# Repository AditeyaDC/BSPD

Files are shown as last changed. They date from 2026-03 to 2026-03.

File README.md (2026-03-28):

# BSPD RZ-XX6-C/E — Brake System Plausibility Device
**Ashwa Racing 27**  
Designed by Aditeya Sarkar

---

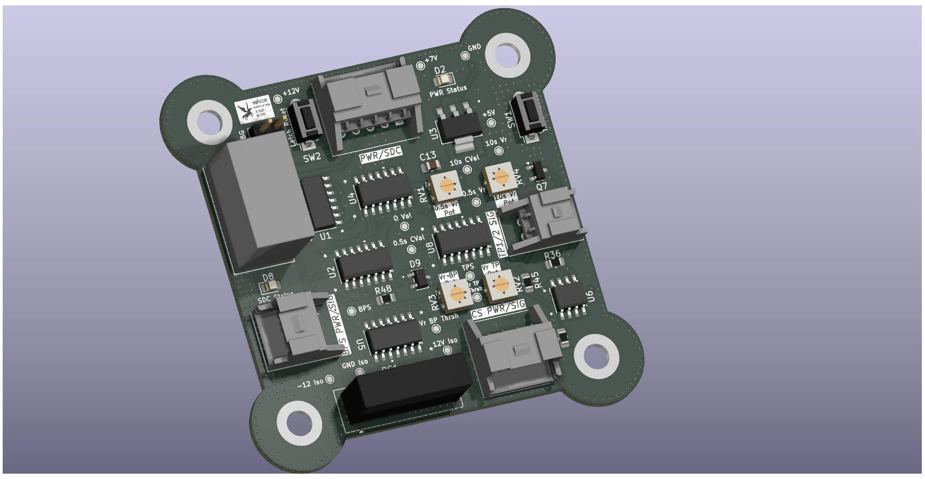
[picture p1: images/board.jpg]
BSPD board


## What is a BSPD?

The Brake System Plausibility Device is a mandatory safety circuit in FSAE/Formula Student vehicles. Its job is to cut power to the motor (via the Shutdown Circuit / SDC) if the driver simultaneously applies heavy braking and demands significant throttle — a condition that should never happen during normal operation and indicates either a pedal fault or a stuck throttle.

This design targets the **FSG CV+EV rules** (with CV mode support via a jumper) and is built entirely out of discrete analog logic — no microcontroller involved.

---

## Block Diagram / Signal Flow

```
Connectors (BPS, TPS, SDC)
        │
        ▼
Current Sensor (EV only)          ←── Biasing circuit converts ±4V diff → 0.5–4.5V
        │
        ▼
Implausibility/Plausibility Check  ←── 500ms timer + 10s timer + comparators
        │
        ▼
SCS Check (Short Circuit Safety)
        │
        ▼
Reset System (SR latch + Power-on reset)
        │
        ▼
Relay (SDC_OUT → cuts motor power / fuel pump)
        │
        ▼
Back to Connectors
```

> Signal flow as annotated in the schematic (Sheet 1/9)

---

## Schematic Overview

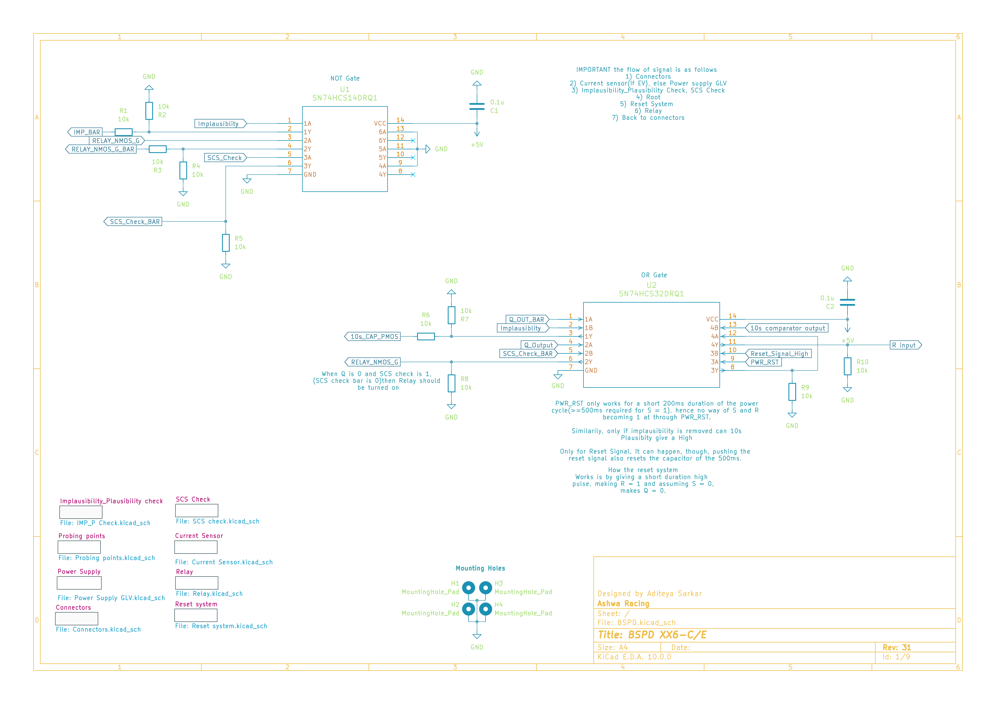
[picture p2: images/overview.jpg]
BSPD Top-Level Overview


The top-level sheet ties everything together. The core logic sits around a **SN74HCS14DRQ1** (Schmitt-trigger inverter, U1) and a **SN74HCS32DRQ1** (OR gate, U2), with the relay controlled by a NMOS gate driven off `RELAY_NMOS_G_BAR`.

---

## Subsystems

### 1. Power Supply

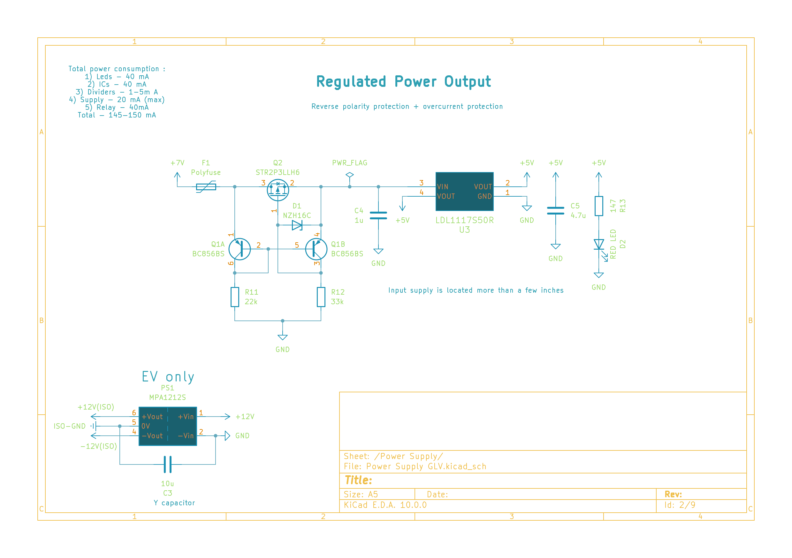
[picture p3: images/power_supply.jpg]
Power Supply


Input is +7V from the car's GLV (Grounded Low Voltage) supply. The board generates a regulated **+5V rail** using an **LDL1117S50R** LDO. Protection is handled by:

- **F1** — Polyfuse for overcurrent  
- **Q2 (STR2P3LLH6)** — P-channel MOSFET for reverse polarity protection, driven by a BC856BS transistor pair (Q1A/Q1B)
- **D1 (NZH16C)** — Zener clamp

For EV operation, isolated ±12V rails are generated via an **MPA1212S** DC-DC isolator (PS1), referenced to ISO-GND, with a Y-capacitor (C3, 10µF) for common-mode filtering.

Total board power budget: ~145–150mA (LEDs 40mA + ICs 40mA + dividers ~5mA + relay 40mA + misc).

---

### 2. Implausibility & Plausibility Check

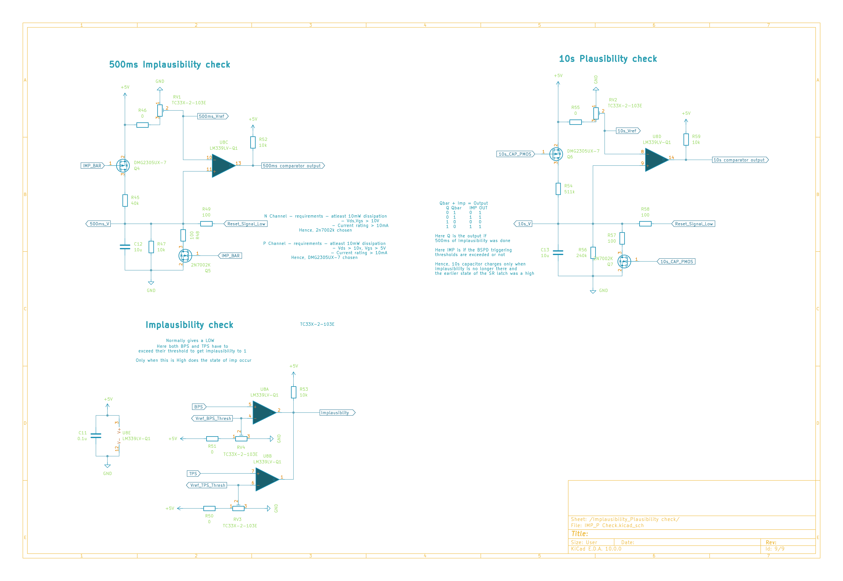
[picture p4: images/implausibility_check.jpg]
Implausibility Check


This is the heart of the BSPD logic. Three comparator circuits run in parallel:

**Implausibility Check** (bottom-left, Sheet 9)  
- Uses **TC33X-2-103E** references and **LM339LV-Q1** comparators
- Both BPS (brake pressure) and TPS (throttle position) must exceed their respective thresholds simultaneously to flag implausibility
- Output: `Implausibility` signal (HIGH = fault)

**500ms Implausibility Timer** (top-left, Sheet 9)  
- Uses a **DMG2305UX-7** complementary MOSFET pair to charge/discharge a capacitor (C12, 10µF + C13) at a controlled rate
- When implausibility is sustained for >500ms, `500ms comparator output` goes HIGH
- The DWC2305UX-7 N-channel requirements: Vth ~1V, Ids up to 10mA → 2N7002K used
- The P-channel: Vth ~−1V, Ids ~10mA → same DWC2305UX-7 (check datasheet for exact variant)

**10s Plausibility Timer** (top-right, Sheet 9)  
- Similar RC-based timing circuit; capacitor (C13) only charges when implausibility is active
- Output: `10s comparator output` — used to latch the fault via the SR latch if the 10s window is exceeded
- `Reset_Signal_Low` can discharge the cap and reset state

---

### 3. Memory Element (SR Latch) + Power Reset

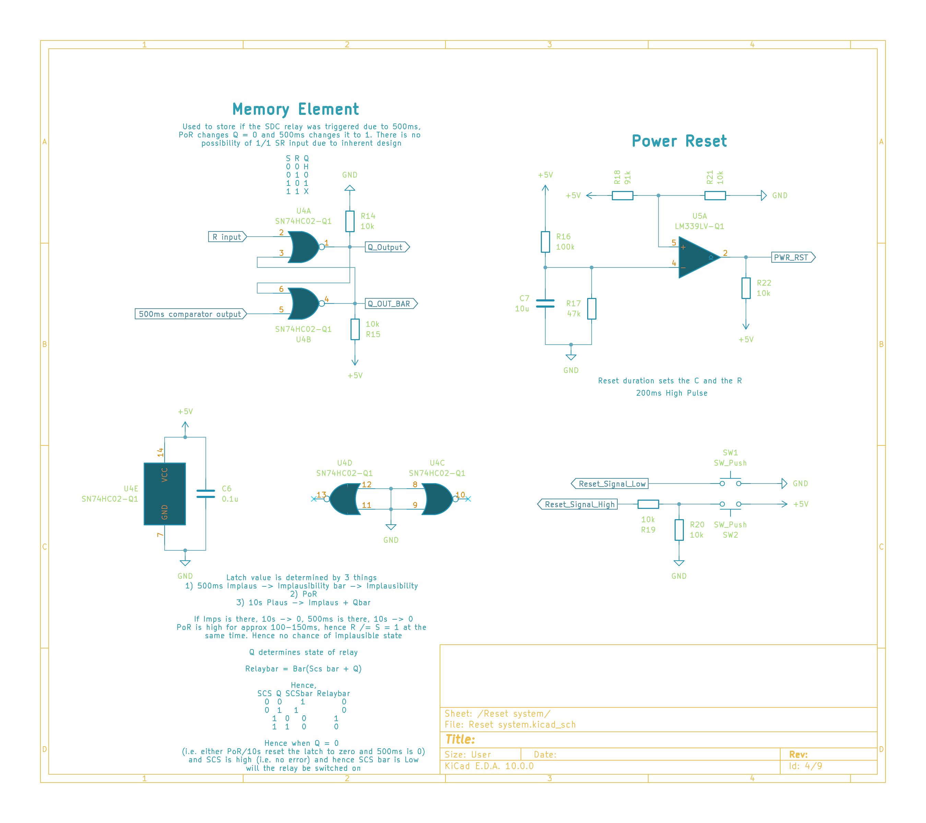
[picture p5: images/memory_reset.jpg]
Memory Element and Reset


**SR Latch** (Sheet 4, left)  
Built from **SN74HC02-Q1** NOR gates (U4A/U4B):

| S (500ms) | R | Q |
|:---:|:-:|:-:|
| 0 | 0 | Hold |
| 0 | 1 | 0 |
| 1 | 0 | 1 |

Q drives `Q_Output` and `Q_OUT_BAR`. The relay state is: `Relaybar = NOR(SCS_bar, Q)`.

So the SDC relay opens (cuts power) only when Q = 0 and SCS_bar is LOW — i.e., no fault and no short circuit detected.

**Power-on Reset** (Sheet 4, right)  
Uses an **LM339LV-Q1** comparator (U5A) with R16 (100k), R17 (47k), and C7 (10µF) to generate a ~200ms HIGH pulse on `PWR_RST` at power-on. This forces the latch into a known state (R = 1 momentarily → Q = 0). Once past the PoR window, R → 0 and normal latch operation resumes.

Two push-buttons (SW1, SW2) provide manual `Reset_Signal_High` / `Reset_Signal_Low` for bench testing.

---

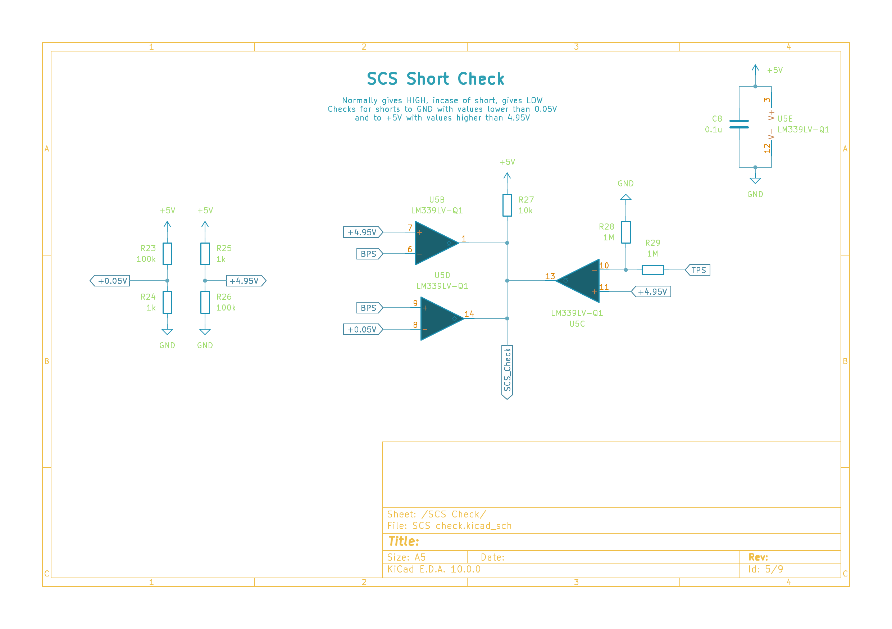
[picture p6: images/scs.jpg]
SCS Check


### 4. SCS Short Circuit Check

The SCS (Short Circuit Safety) check uses **LM339LV-Q1** comparators (U5B/U5D/U5C) to detect wiring faults — specifically shorts to GND (<0.05V) or shorts to +5V (>4.95V) on the BPS and TPS lines.

- Normally: `SCS_Check` = HIGH (no fault)
- On short detection: goes LOW, which blocks the relay from closing regardless of Q

Thresholds set by 100k/1k voltage divider pairs on each input.

---

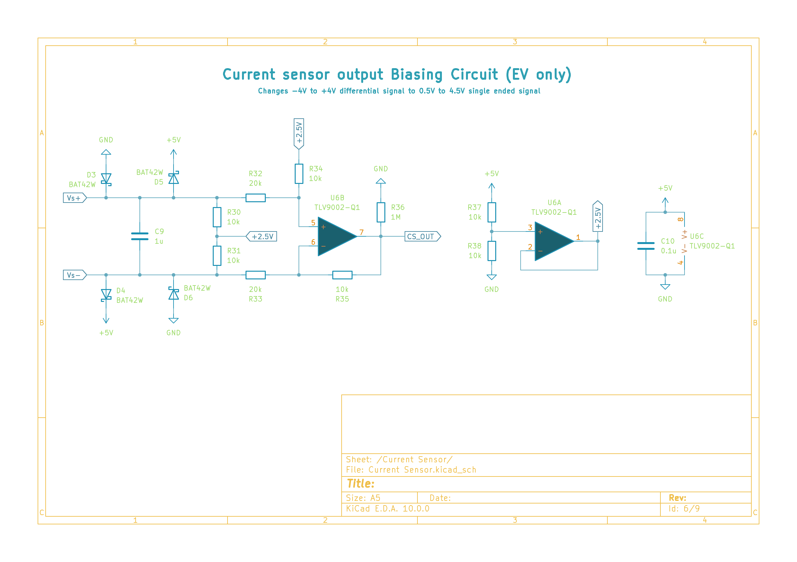
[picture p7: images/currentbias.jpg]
Current Sensor Biasing


### 5. Current Sensor (HB0 300) Biasing (EV Only)

The current sensor (external, connected via J3) outputs a differential signal in the ±4V range. Sheet 6 handles the level shift to a 0.5V–4.5V single-ended signal suitable for the comparators.

- BAT42W Schottky diodes (D3–D6) clamp Vs+ and Vs− to the 0–5V range
- **TLV9002-Q1** op-amps (U6A/U6B) in a difference amplifier config with a +2.5V mid-rail reference
- Output: `CS_OUT` → fed into the implausibility comparator as the throttle-side signal in EV mode
- A jumper on Sheet 8 allows bypassing this for CV (combustion) mode, where TPS1_IN connects directly

---

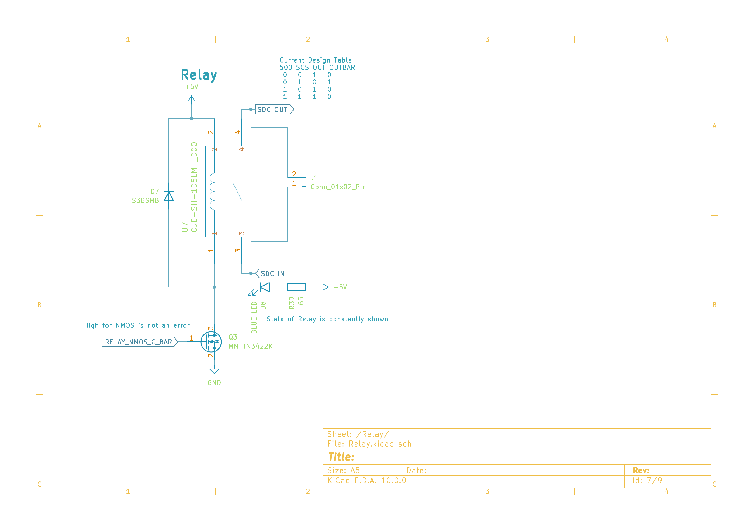
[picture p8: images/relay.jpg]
Relay


### 6. Relay

The SDC relay is an **OJE-SH-105LMH** (U7), driven by an NMOS switch (**MMFTN3422K**, Q3) on the low side. `SDC_OUT` drives the relay coil. A **S3B5MB** diode (D7) provides flyback protection. A blue LED gives constant visual indication of relay state.

---

### 7. Connectors

All external signals come through **TE Connectivity 1744426-series** connectors:

| Connector | Signals |
|---|---|
| J2 (1744426-5) | PWR_FLAG (+7V), GND, +12V, SDC_IN, SDC_OUT |
| J3 (1744426-4) | +12V(ISO), Vs−, Vs+, −12V(ISO) |
| J4 (1744426-3) | GND, BPS_IN, +12V |
| J5 (1744426-2) | TPS1_IN, GND |

BPS scaling: R42 (200Ω) + R43 (430Ω) divider sets `BPS_SCLD` in the 0.88V–4.4V window.  
ESD protection on BPS line via **ESDCAN01-2BLY** (D9).

---

### 8. Probing Points

16 dedicated test points for bench validation:

| TP | Net | TP | Net |
|----|-----|----|-----|
| TP1 | +12V | TP2 | Vref_BPS_Thresh |
| TP3 | +7V | TP4 | 500ms_Vref |
| TP5 | +5V | TP6 | 10s_Vref |
| TP7 | GND | TP8 | Vref_TPS_Thresh |
| TP9 | +12V ISO | TP10 | 10s_V |
| TP11 | GND ISO | TP12 | Q_Output |
| TP13 | −12V ISO | TP14 | 500ms_V |
| TP15 | BPS | TP16 | TPS |

---

## Key ICs

| Part | Function |
|---|---|
| SN74HCS14DRQ1 | Schmitt-trigger inverter (signal conditioning) |
| SN74HCS32DRQ1 | OR gate (implausibility logic) |
| SN74HC02-Q1 | NOR gate SR latch (fault memory) |
| LM339LV-Q1 | Quad comparator (thresholds, SCS, power reset) |
| TLV9002-Q1 | Op-amp (current sensor biasing) |
| LDL1117S50R | 5V LDO regulator |
| MPA1212S | ±12V isolated DC-DC (EV) |
| OJE-SH-105LMH | SDC relay |
| MMFTN3422K | N-channel MOSFET (relay driver) |
| DMG2305UX-7 | Complementary MOSFET pair (timer charging) |

---

## KiCad Version Compatibility

This schematic was designed in **KiCad EDA 10.0.0**.

If you're on KiCad v9 and need to open these files, a downconverted v9-compatible version is available — reach out or raise an issue. The downconversion removes v10-specific fields (like `uuid` blocks and certain footprint attributes) that cause parse errors on older installs.

---

## Repo Structure

```
BSPD/
├── BSPD.kicad_sch              # Top-level schematic
├── Power Supply GLV.kicad_sch
├── Probing points.kicad_sch
├── Reset system.kicad_sch
├── SCS check.kicad_sch
├── Current Sensor.kicad_sch
├── Relay.kicad_sch
├── Connectors.kicad_sch
├── IMP_P_Check.kicad_sch       # Implausibility/Plausibility check
└── README.md
```

---

## Team

**Ashwa Racing — 27**  
R.V. College of Engineering, Bangalore  

Electrical & Testing Subsystem  
Schematic design: Aditeya Sarkar

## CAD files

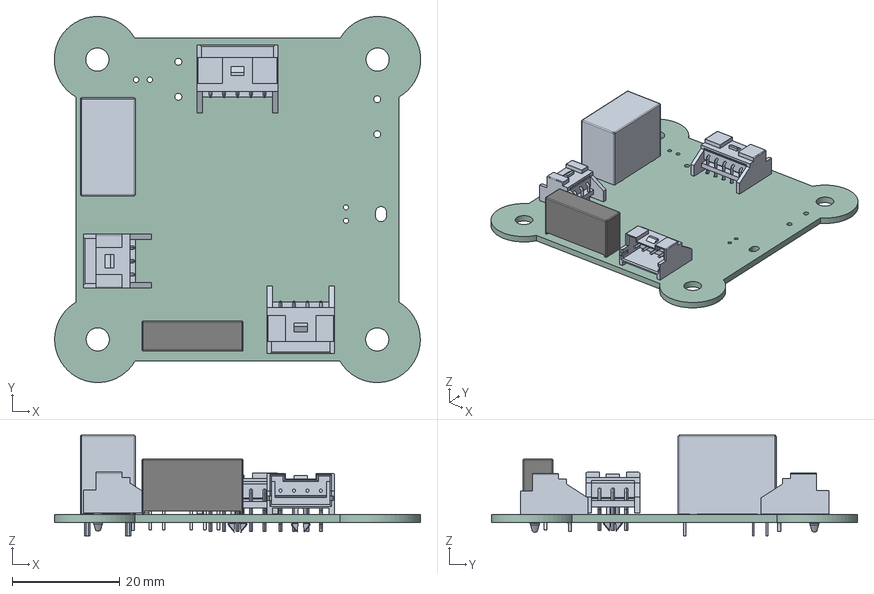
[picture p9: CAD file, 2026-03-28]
BSPD.step
68.0 x 67.9 x 18.7 mm
OJ-SH-105LM,000
Converter_DCDC_XP_POWER-IAxxxxS_THT
BSPD_PCB

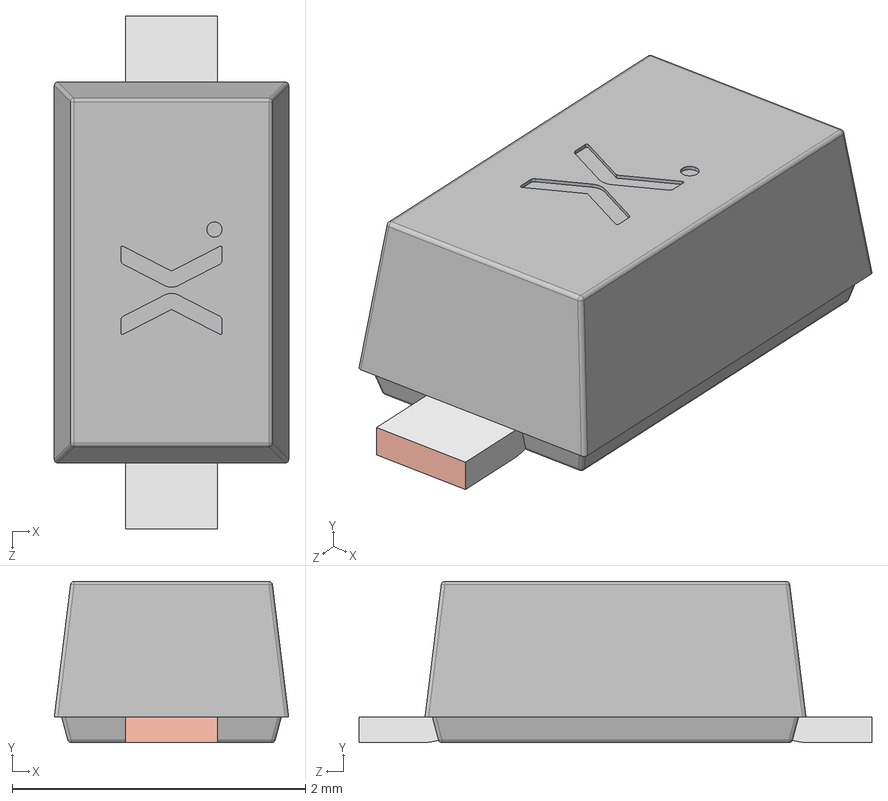
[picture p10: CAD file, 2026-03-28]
KiCad/9.0/3dmodels/SOD123F.step
1.60 x 1.10 x 3.50 mm
SOD123F Lead
SOD123F lower body
SOD123F upper body

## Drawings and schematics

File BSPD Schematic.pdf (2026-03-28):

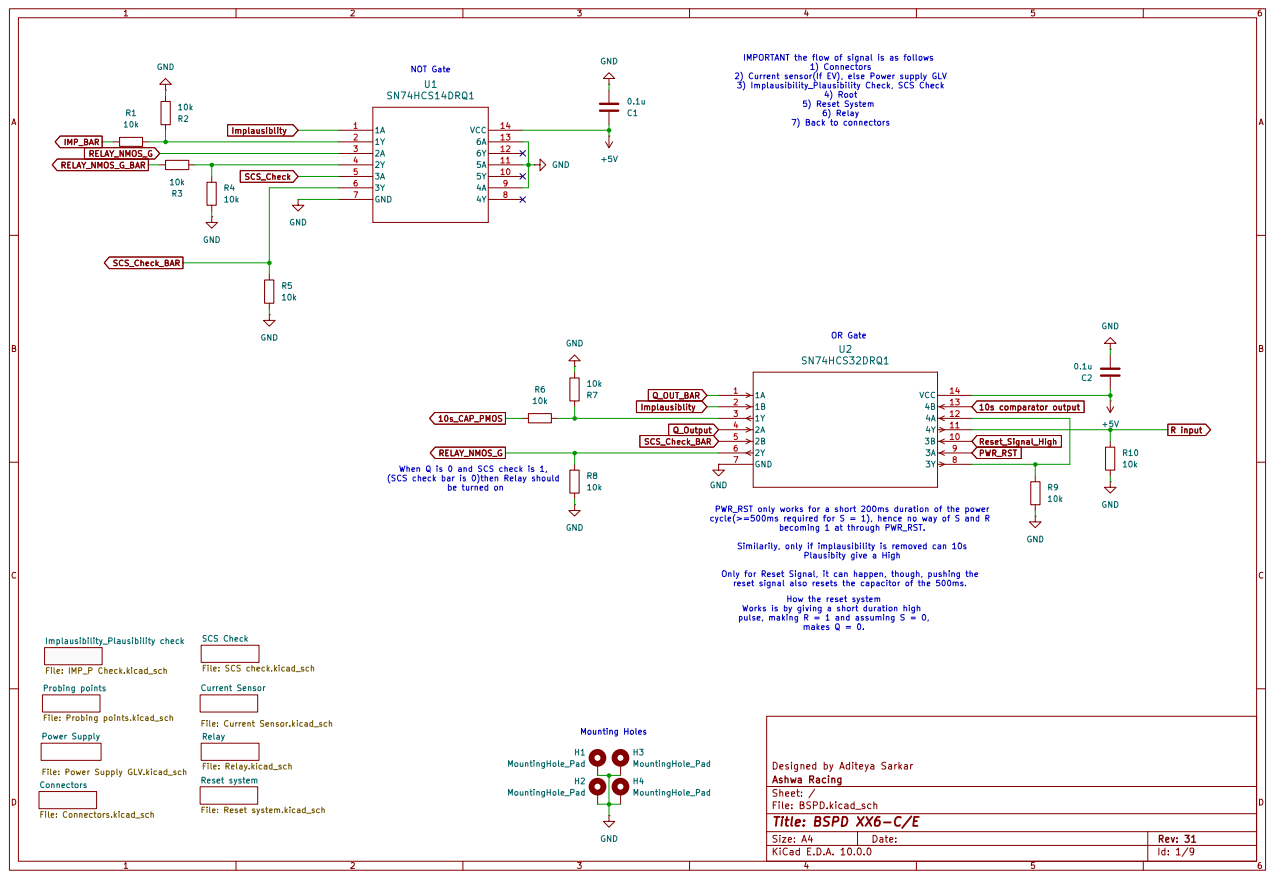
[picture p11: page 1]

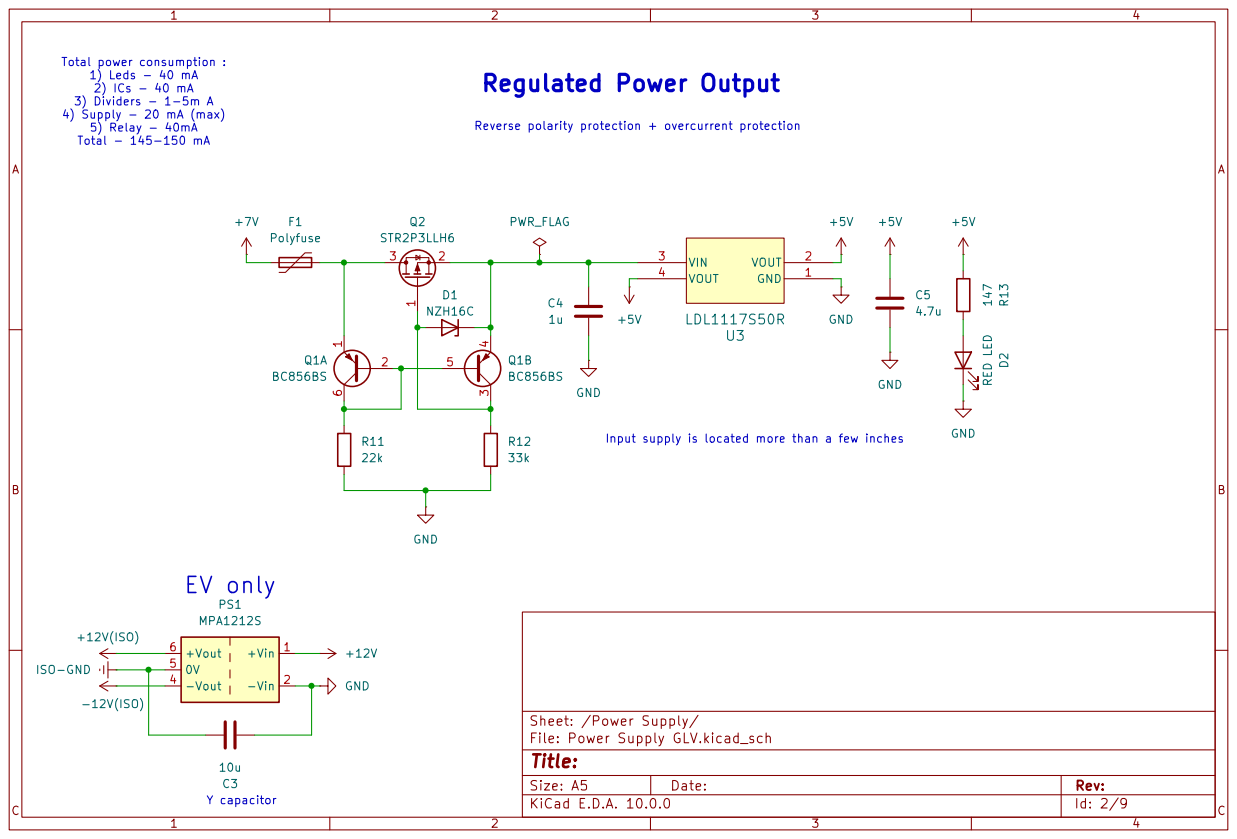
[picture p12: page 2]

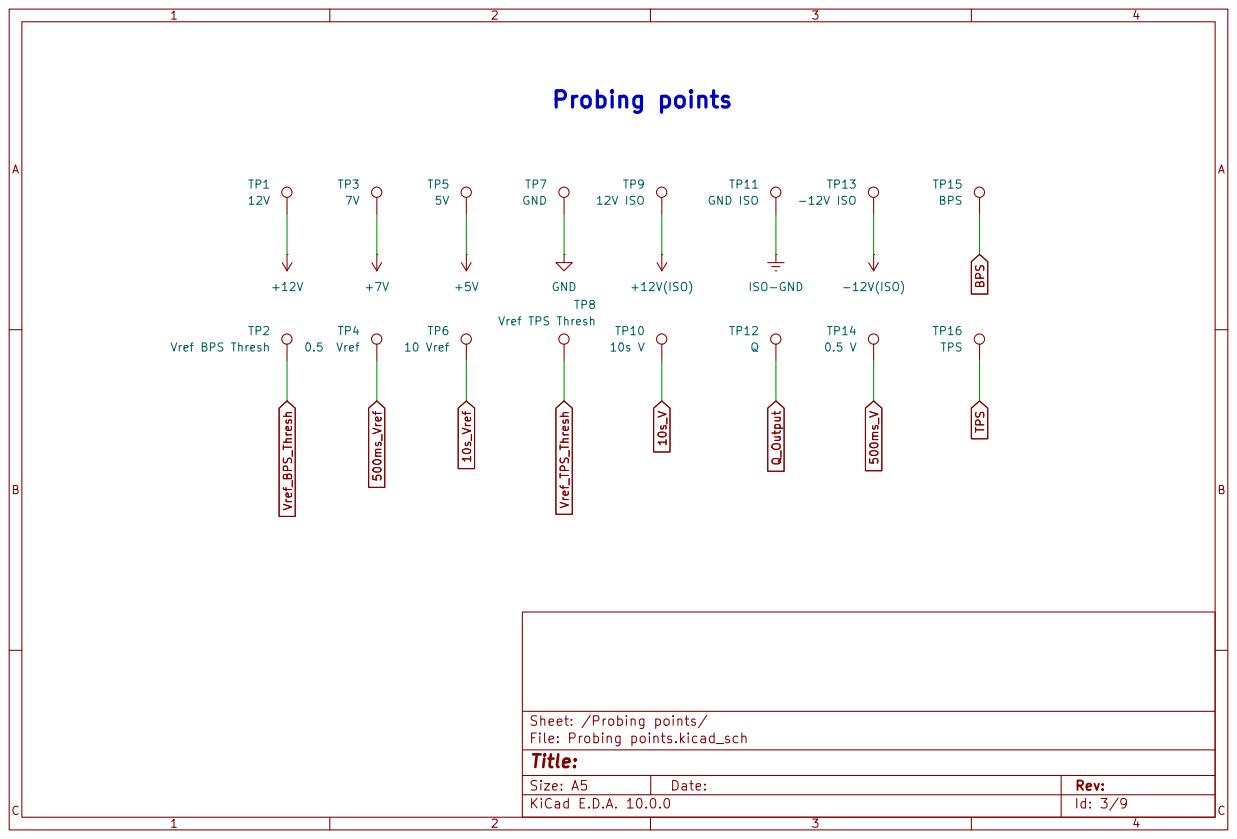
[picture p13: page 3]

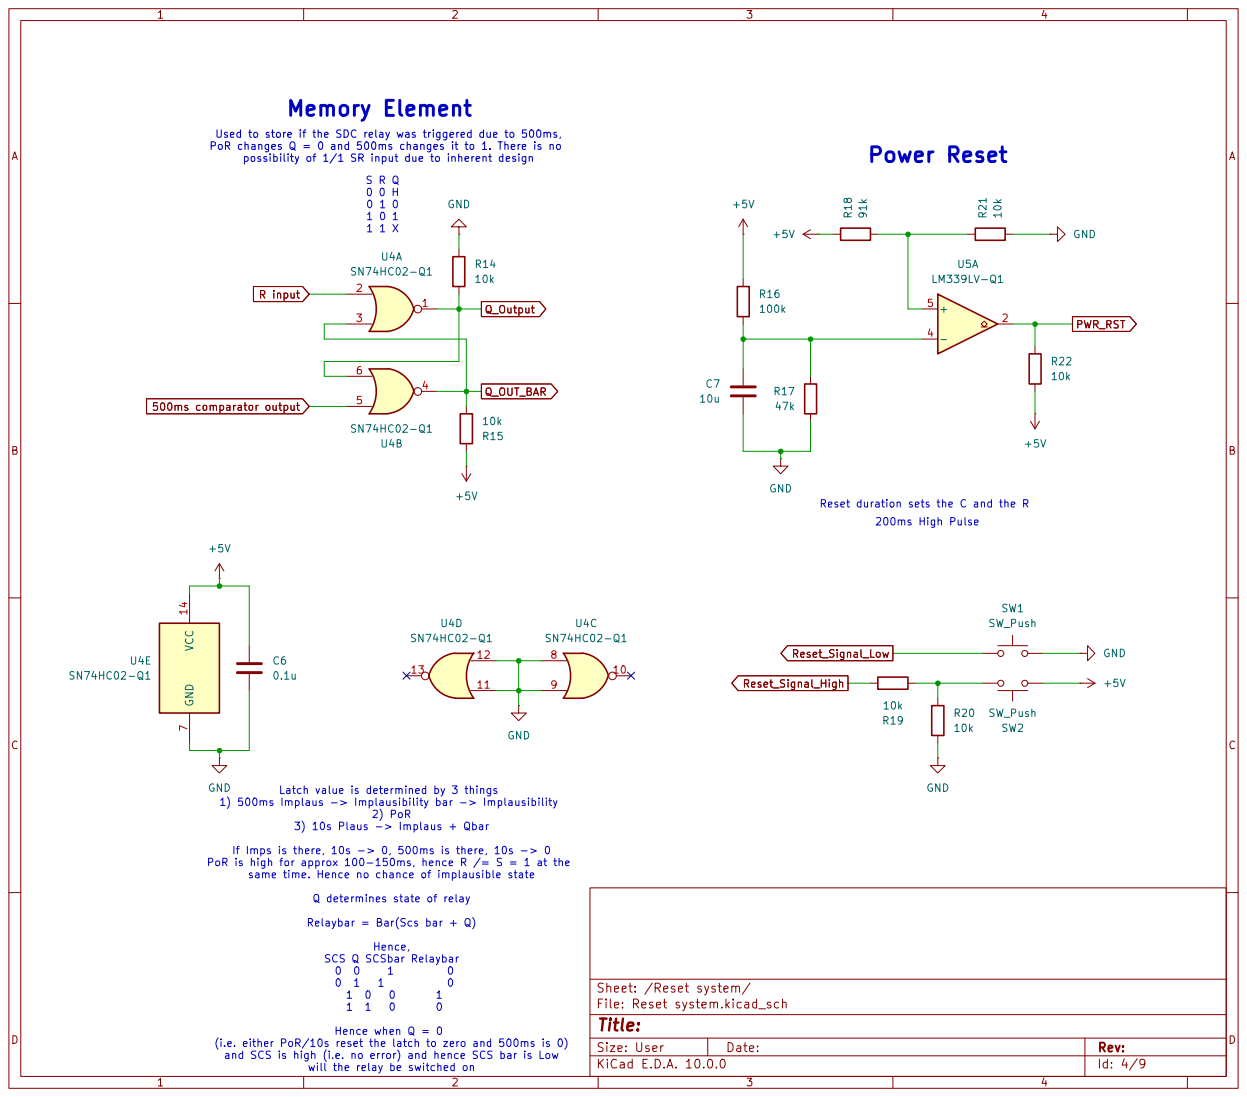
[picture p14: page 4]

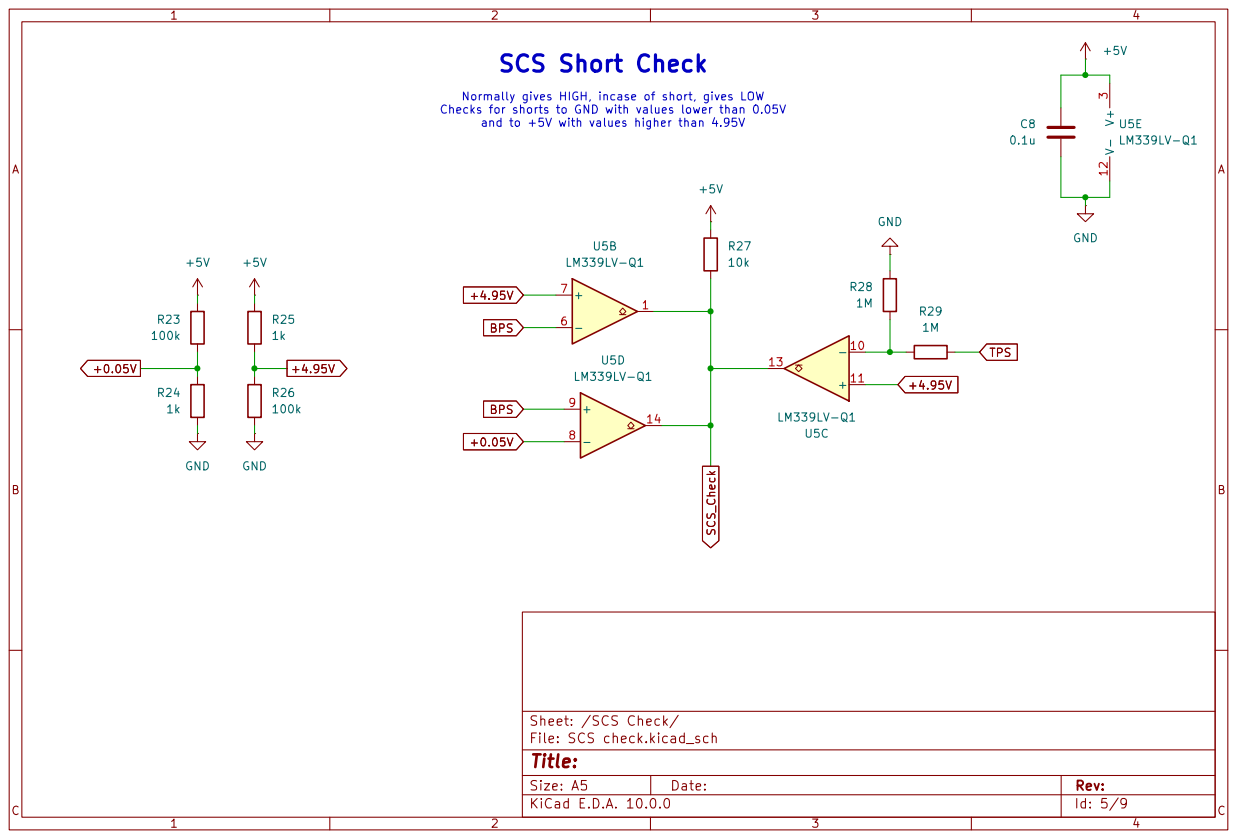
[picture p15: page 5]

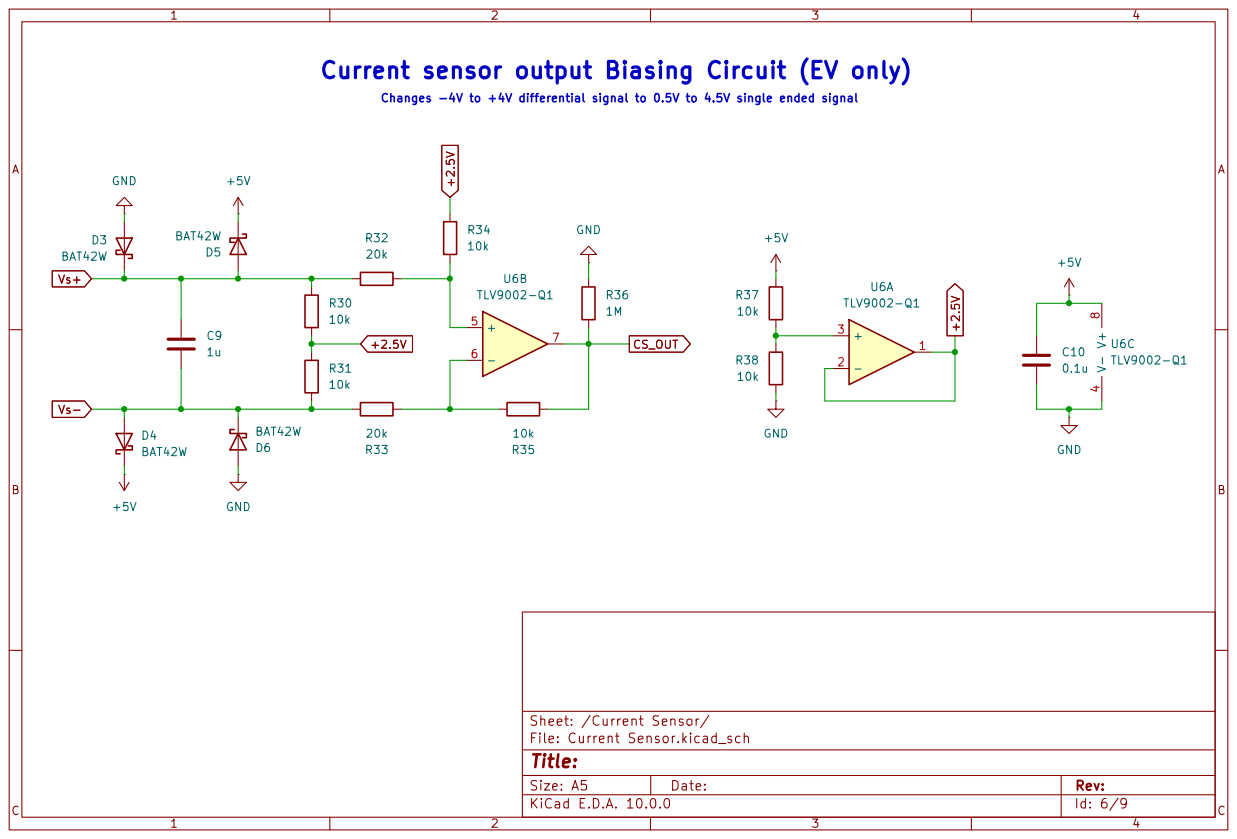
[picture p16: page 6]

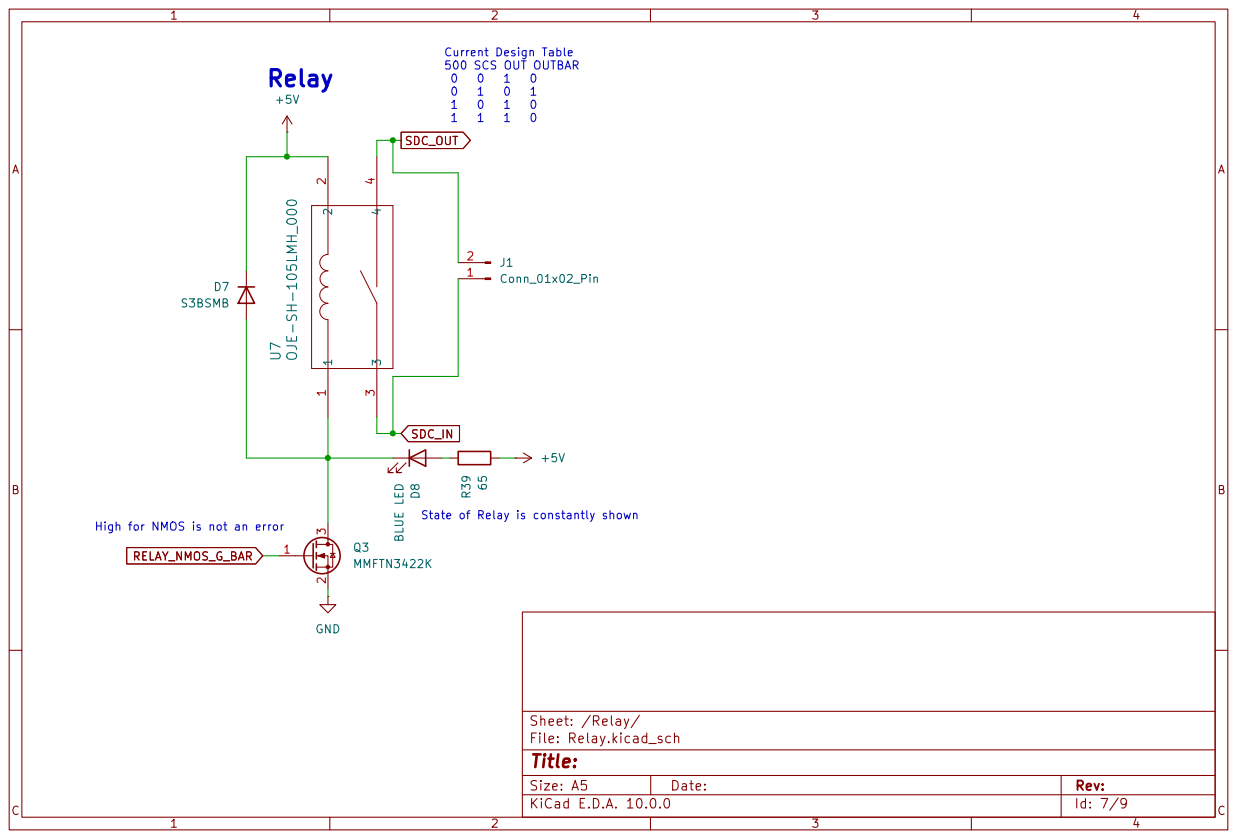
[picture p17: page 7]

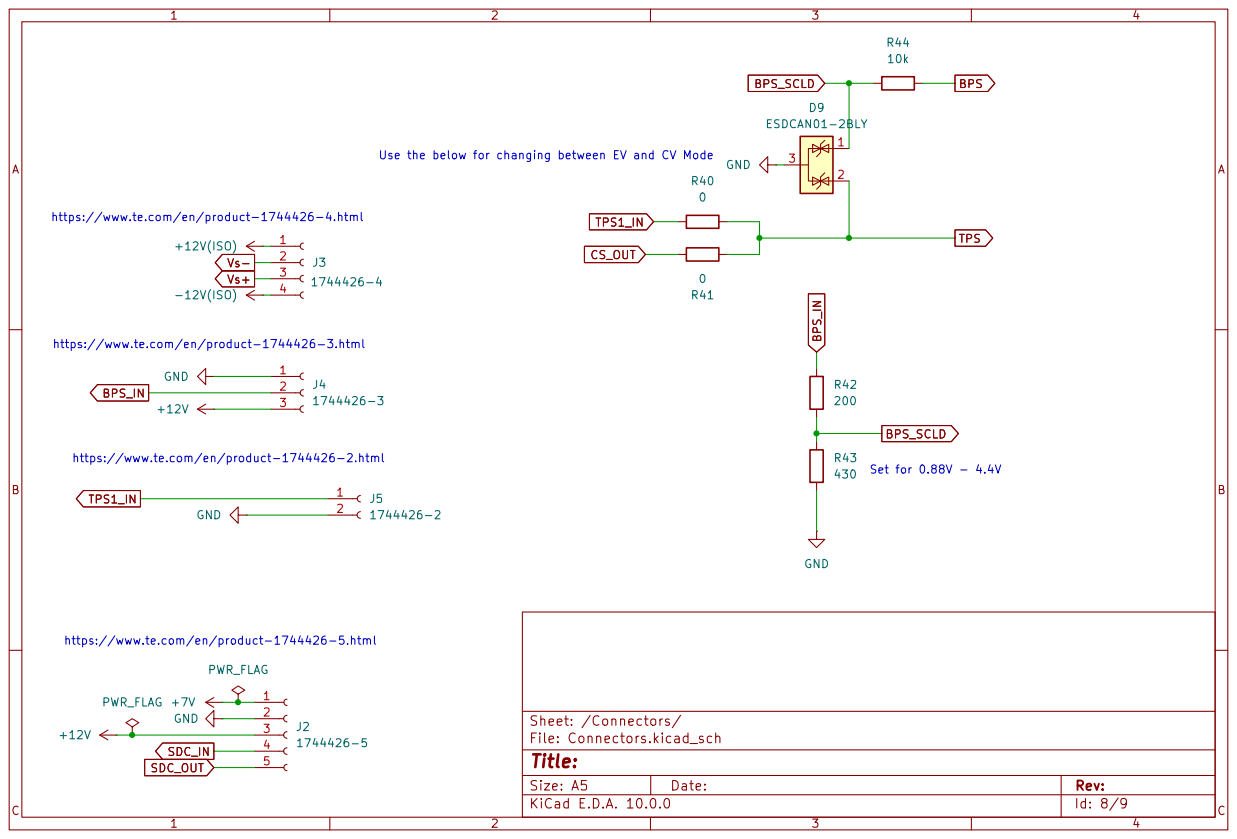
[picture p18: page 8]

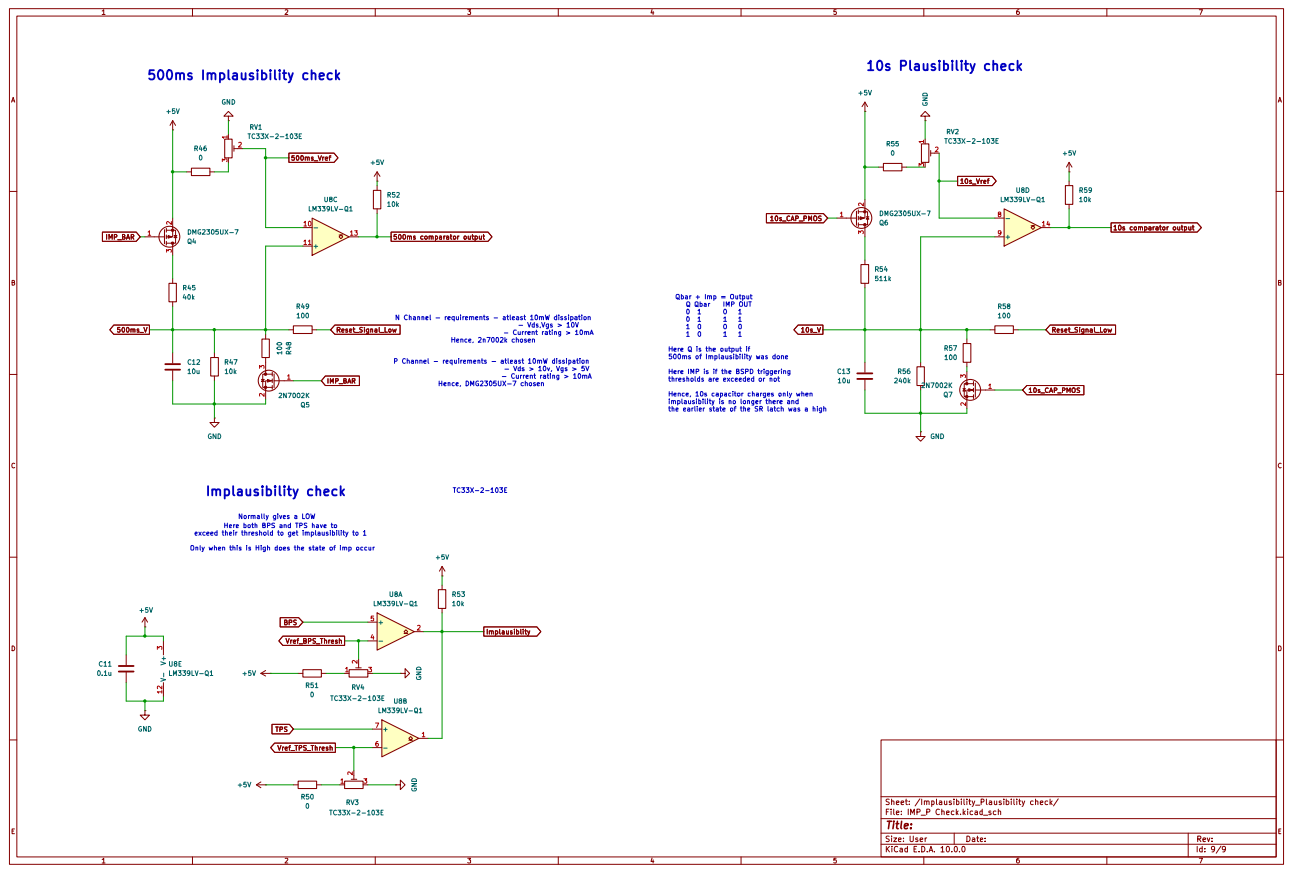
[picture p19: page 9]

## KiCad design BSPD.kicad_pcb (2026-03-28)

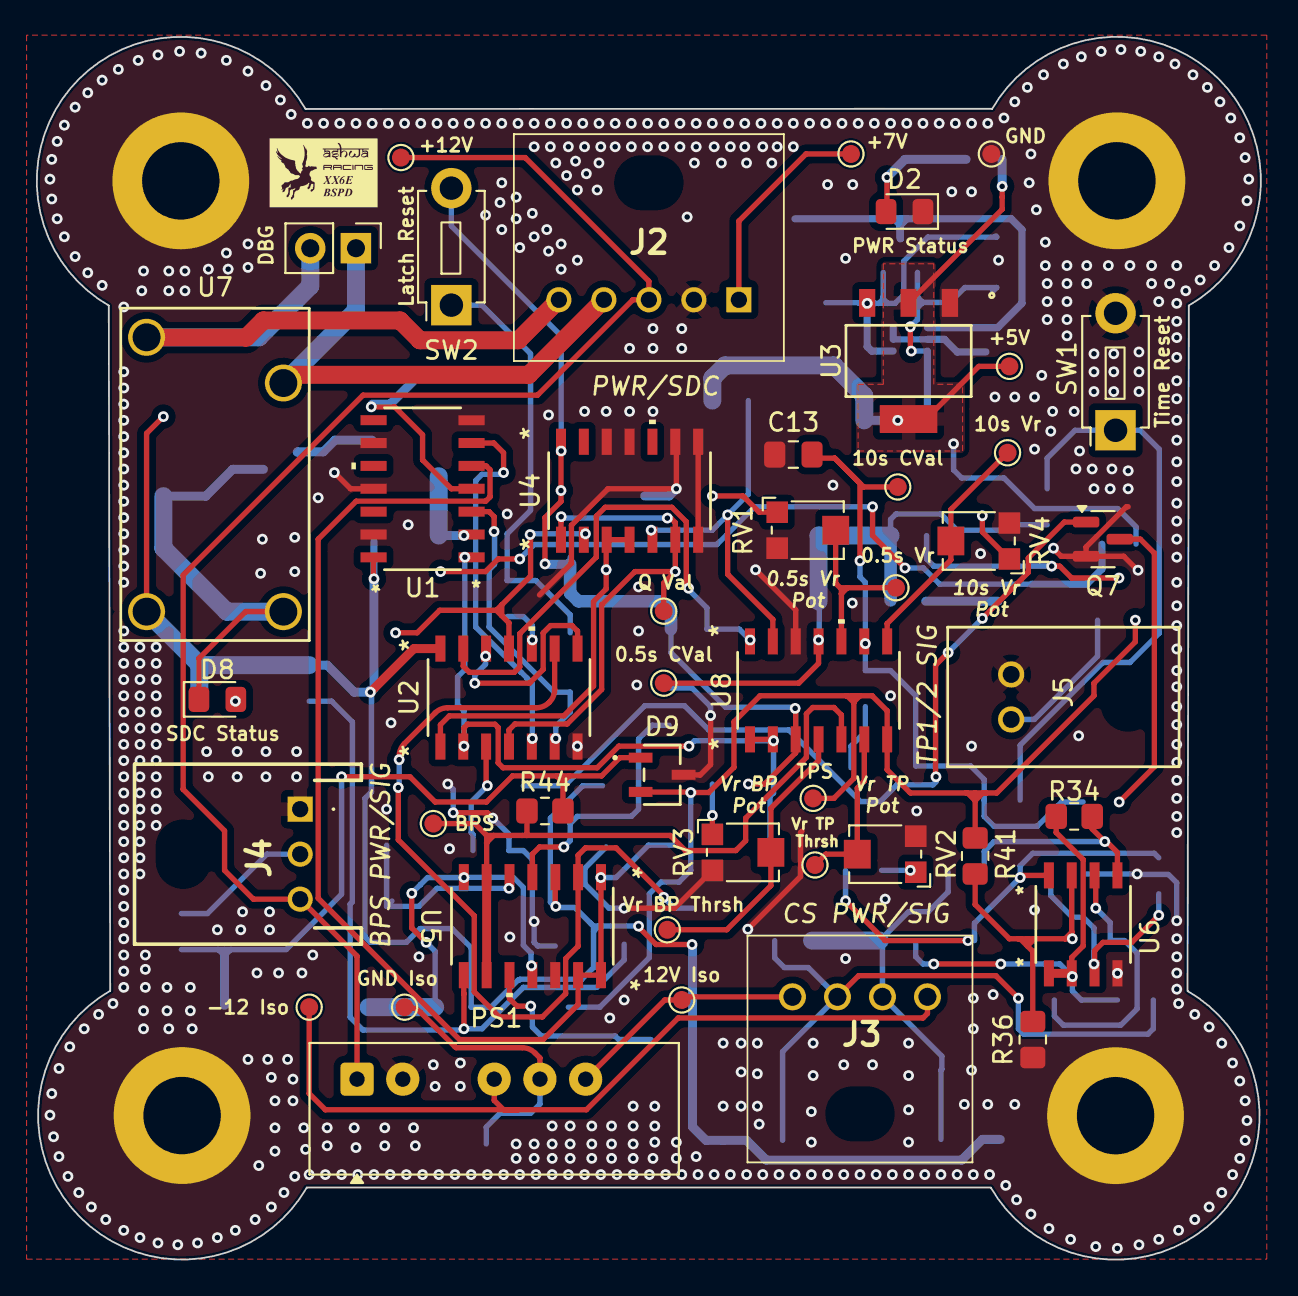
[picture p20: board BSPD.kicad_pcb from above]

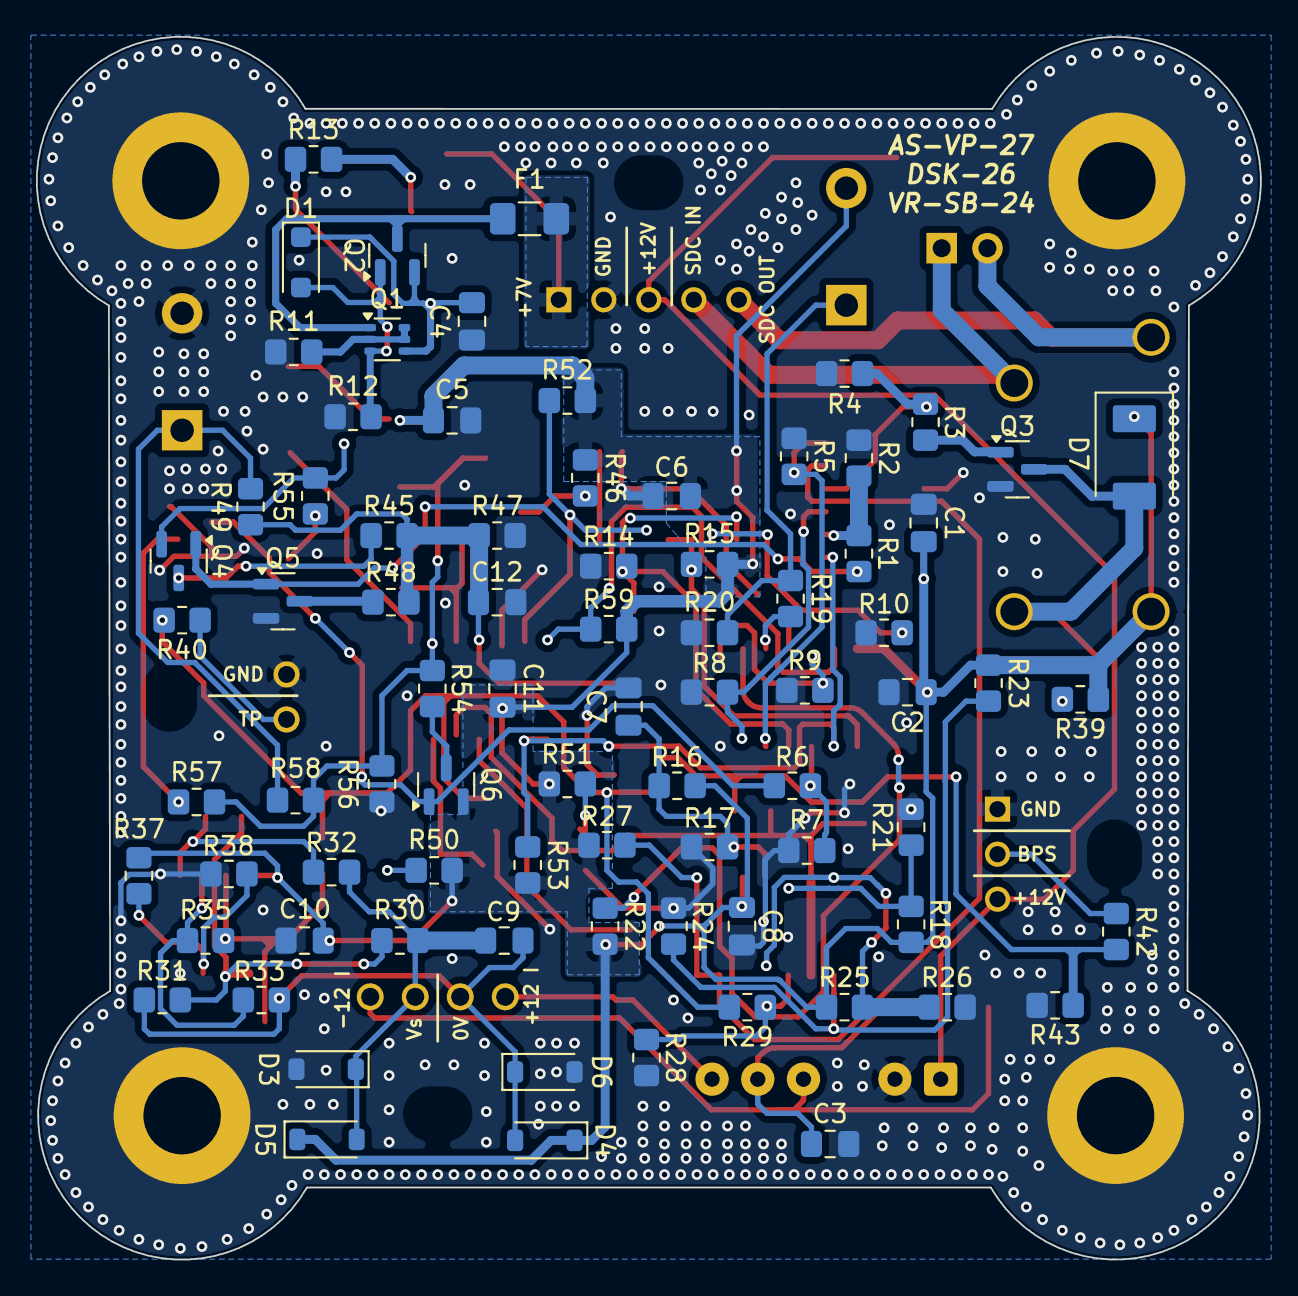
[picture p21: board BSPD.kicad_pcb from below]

Board: 2 copper layers, 68.0 x 67.9 mm, 129 parts (80 on the bottom side), 67 nets.

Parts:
C1, C2, C6, C8, C10, C11: 0.1u; C_0805_2012Metric_Pad1.18x1.45mm_HandSolder
C3, C7, C12, C13: 10u; C_0805_2012Metric_Pad1.18x1.45mm_HandSolder
C4, C9: 1u; C_0805_2012Metric_Pad1.18x1.45mm_HandSolder
C5: 4.7u; C_0805_2012Metric_Pad1.18x1.45mm_HandSolder
D1: NZH16C; D_SOD-123F
D2: RED LED; LED_0805_2012Metric_Pad1.15x1.40mm_HandSolder
D3, D4, D5, D6: BAT42W; D_SOD-123
D7: S3BSMB; P26_DO-214AA_SMB
D8: BLUE LED; LED_0805_2012Metric_Pad1.15x1.40mm_HandSolder
D9: ESDCAN01-2BLY; SOT_01-2BLY_STM
F1: Polyfuse; Fuse_1206_3216Metric_Pad1.42x1.75mm_HandSolder
H1, H2, H3, H4: MountingHole_Pad; MountingHole_4.3mm_M4_ISO7380_Pad
J1: Conn_01x02_Pin; PinHeader_1x02_P2.54mm_Vertical
J2: 1744426-5; 17444265
J3: 1744426-4; 17444264
J4: 1744426-3; 17444263
J5: 1744426-2; CONN2_1744426-2
PS1: MPA1212S; Converter_DCDC_XP_POWER-IAxxxxS_THT
Q1: BC856BS; SOT-363_SC-70-6
Q2: STR2P3LLH6; SOT-23
Q3: MMFTN3422K; SOT-23
Q4, Q6: DMG2305UX-7; SOT-23
Q5, Q7: 2N7002K; SOT-23
R1, R2, R3, R4, R5, R6, R7, R8, R9, R10, R14, R15, R19, R20, R21, R22, R27, R30, R31, R34, R35, R37, R38, R40, R41, R44, R46, R47, R50, R51, R52, R53, R55, R59: 10k; R_0805_2012Metric_Pad1.20x1.40mm_HandSolder
R11: 22k; R_0805_2012Metric_Pad1.20x1.40mm_HandSolder
R12: 33k; R_0805_2012Metric_Pad1.20x1.40mm_HandSolder
R13: 147; R_0805_2012Metric_Pad1.20x1.40mm_HandSolder
R16, R23, R26: 100k; R_0805_2012Metric_Pad1.20x1.40mm_HandSolder
R17: 47k; R_0805_2012Metric_Pad1.20x1.40mm_HandSolder
R18: 91k; R_0805_2012Metric_Pad1.20x1.40mm_HandSolder
R24, R25: 1k; R_0805_2012Metric_Pad1.20x1.40mm_HandSolder
R28, R29, R36: 1M; R_0805_2012Metric_Pad1.20x1.40mm_HandSolder
R32, R33: 20k; R_0805_2012Metric_Pad1.20x1.40mm_HandSolder
R39: 65; R_0805_2012Metric_Pad1.20x1.40mm_HandSolder
R42: 200; R_0805_2012Metric_Pad1.20x1.40mm_HandSolder
R43: 430; R_0805_2012Metric_Pad1.20x1.40mm_HandSolder
R45: 40k; R_0805_2012Metric_Pad1.20x1.40mm_HandSolder
R48, R49, R57, R58: 100; R_0805_2012Metric_Pad1.20x1.40mm_HandSolder
R54: 511k; R_0805_2012Metric_Pad1.20x1.40mm_HandSolder
R56: 240k; R_0805_2012Metric_Pad1.20x1.40mm_HandSolder
RV1, RV2, RV3, RV4: TC33X-2-103E; Potentiometer_Bourns_TC33X_Vertical
SW1, SW2: SW_Push; SW_PUSH_1P1T_6x3.5mm_H4.3_APEM_MJTP1243
TP1: 12V; TestPoint_Pad_D1.0mm
TP2: Vref BPS Thresh; TestPoint_Pad_D1.0mm
TP3: 7V; TestPoint_Pad_D1.0mm
TP4: 0.5 Vref; TestPoint_Pad_D1.0mm
TP5: 5V; TestPoint_Pad_D1.0mm
TP6: 10 Vref; TestPoint_Pad_D1.0mm
TP7: GND; TestPoint_Pad_D1.0mm
TP8: Vref TPS Thresh; TestPoint_Pad_D1.0mm
TP9: 12V ISO; TestPoint_Pad_D1.0mm
TP10: 10s V; TestPoint_Pad_D1.0mm
TP11: GND ISO; TestPoint_Pad_D1.0mm
TP12: Q; TestPoint_Pad_D1.0mm
TP13: -12V ISO; TestPoint_Pad_D1.0mm
TP14: 0.5 V; TestPoint_Pad_D1.0mm
TP15: BPS; TestPoint_Pad_D1.0mm
TP16: TPS; TestPoint_Pad_D1.0mm
U1: SN74HCS14DRQ1; SOIC_S14DR_TEX
U2: SN74HCS32DRQ1; SOIC_S14DR_TEX
U3: LDL1117S50R; SOT223_STM
U4: SN74HC02-Q1; SOIC_S14DR_TEX
U5, U8: LM339LV-Q1; SOIC_S14DR_TEX
U6: TLV9002-Q1; SOIC8_D_TEX
U7: OJE-SH-105LMH_000; RELAY4_OJE-SH-105LMH_000_TEC

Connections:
10s comparator output: R59.1, U2.13 (4B), U8.14
10s_CAP_PMOS: Q6.1 (G), Q7.1 (G), R6.1
10s_V: C13.1, R54.2, R56.1, R57.1, R58.1, TP10.1, U8.9 (+)
10s_Vref: RV4.2, TP6.1, U8.8 (-)
500ms comparator output: R52.2, U4.5, U8.13
500ms_V: C12.1, R45.2, R47.1, R48.2, R49.1, TP14.1, U8.11 (+)
500ms_Vref: RV1.2, TP4.1, U8.10 (-)
+0.05V: R23.2, R24.1, U5.8 (-)
+2.5V: R30.2, R31.1, R34.2, U6.1, U6.2 (-)
+4.95V: R25.2, R26.1, U5.7 (+), U5.11 (+)
+5V: C1.1, C2.1, C5.1, C6.1, C8.1, C10.1, C11.1, D4.1 (K), D5.1 (K), D7.1 (K), Q4.2 (S), Q6.2 (S), R13.1, R15.1, R16.1, R18.1, R22.2, R23.1, R25.1, R27.2, R37.1, R39.1, R46.1, R50.1, R51.1, R52.1, R53.2, R55.1, R59.2, SW2.2, TP5.1, U1.14 (VCC), U2.14 (VCC), U3.2 (VOUT), U3.4 (VOUT), U4.14 (VCC), U5.3 (V+), U6.8 (V+), U7.2, U8.3 (V+)
+7V: F1.1, J2.1, TP3.1
+12V: J2.3, J4.3, PS1.1 (+Vin), TP1.1
+12V(ISO): J3.1, PS1.6 (+Vout), TP9.1
-12V(ISO): J3.4, PS1.4 (-Vout), TP13.1
BPS: R44.2, TP15.1, U5.6 (-), U5.9 (+), U8.5 (+)
BPS_IN: J4.2, R42.1
BPS_SCLD: D9.1 (K), R42.2, R43.1, R44.1
CS_OUT: R35.1, R36.2, R41.2, U6.7
GND: C1.2, C2.2, C3.2, C4.2, C5.2, C6.2, C7.2, C8.2, C10.2, C11.2, C12.2, C13.2, D2.1 (K), D3.2 (A), D6.2 (A), D9.3 (A), H1.1, H2.1, H3.1, H4.1, J2.2, J4.1, J5.2, PS1.2 (-Vin), Q3.2 (S), Q5.2 (S), Q7.2 (S), R2.1, R4.1, R5.1, R7.1, R8.1, R9.1, R10.1, R11.2, R12.2, R14.1, R17.2, R20.2, R21.2, R24.2, R26.2, R28.1, R36.1, R38.2, R43.2, R47.2, R56.2, RV1.3, RV2.3, RV3.3, RV4.3, SW1.2, TP7.1, U1.7 (GND), U1.9 (4A), U1.11 (5A), U1.13 (6A), U2.7 (GND), U3.1 (GND), U4.7 (GND), U4.8, U4.9, U4.11, U4.12, U5.12 (V-), U6.4 (V-), U8.12 (V-)
IMP_BAR: Q4.1 (G), Q5.1 (G), R1.1
ISO-GND: C3.1, PS1.5 (0V), TP11.1
Implausiblity: R53.1, U1.1 (1A), U2.2 (1B), U8.1, U8.2
unnamed: D1.2 (A), Q1.3 (C2), Q2.1 (G), R12.1
unnamed: C4.1, D1.1 (K), Q1.4 (E2), Q2.2 (S), U3.3 (VIN)
unnamed: D2.2 (A), R13.2
unnamed: D7.2 (A), D8.1 (K), Q3.3 (D), U7.1
unnamed: D8.2 (A), R39.2
unnamed: Q1.2 (B1), Q1.5 (B2), Q1.6 (C1), R11.1
unnamed: F1.2, Q1.1 (E1), Q2.3 (D)
unnamed: Q4.3 (D), R45.1
unnamed: Q5.3 (D), R48.1
unnamed: Q6.3 (D), R54.1
unnamed: Q7.3 (D), R57.2
unnamed: R19.2, R20.1, SW2.1
unnamed: R46.2, RV1.1
unnamed: R50.2, RV2.1
unnamed: R51.2, RV3.1
unnamed: R55.2, RV4.1
unnamed: R1.2, R2.2, U1.2 (1Y)
unnamed: R3.2, R4.2, U1.4 (2Y)
unnamed: R6.2, R7.2, U2.3 (1Y)
unnamed: R9.2, U2.8 (3Y), U2.12 (4A)
unnamed: R18.2, R21.1, U5.5 (+)
unnamed: C7.1, R16.2, R17.1, U5.4 (-)
unnamed: R28.2, R29.1, U5.10 (-)
unnamed: R37.2, R38.1, U6.3 (+)
unnamed: R32.2, R34.1, U6.5 (+)
unnamed: R33.1, R35.2, U6.6 (-)
PWR_RST: R22.1, U2.9 (3A), U5.2
Q_OUT_BAR: R15.2, U2.1 (1A), U4.3, U4.4
Q_Output: R14.2, TP12.1, U2.4 (2A), U4.1, U4.6
R input: R10.2, U2.11 (4Y), U4.2
RELAY_NMOS_G: R8.2, U1.3 (2A), U2.6 (2Y)
RELAY_NMOS_G_BAR: Q3.1 (G), R3.1
Reset_Signal_High: R19.1, U2.10 (3B)
Reset_Signal_Low: R49.2, R58.2, SW1.1
SCS_Check: R27.1, U1.5 (3A), U5.1, U5.13, U5.14
SCS_Check_BAR: R5.2, U1.6 (3Y), U2.5 (2B)
SDC_IN: J1.1, J2.4, U7.3
SDC_OUT: J1.2, J2.5, U7.4
TPS: D9.2 (K), R29.2, R40.2, R41.1, TP16.1, U8.7 (+)
TPS1_IN: J5.1, R40.1
Vref_BPS_Thresh: RV3.2, TP2.1, U8.4 (-)
Vref_TPS_Thresh: RV2.2, TP8.1, U8.6 (-)
Vs+: C9.1, D3.1 (K), D5.2 (A), J3.3, R30.1, R32.1
Vs-: C9.2, D4.2 (A), D6.1 (K), J3.2, R31.2, R33.2
